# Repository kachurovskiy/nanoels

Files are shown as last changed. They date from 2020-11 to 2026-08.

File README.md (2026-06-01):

This software and instructions are [provided as is](LICENSE), without warranty of any kind. [🇷🇺 Перевод на русский](https://translate.google.com/translate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), [🇩🇪 deutsche Übersetzung](https://translate.google.com/translate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)

**Design lathe parts in the browser with [LatheCode](https://kachurovskiy.com/lathecode/):** start from sample shapes, dimensions, drawings, saved profiles, or STL meshes; preview the result in 2D/3D; then export STL or G-code for machining. It fits naturally with NanoELS and Modulathe workflows: design the turned profile, inspect the generated toolpath, and run or save G-code for your controller, with drafts and settings kept locally in your browser.

# NanoEls H5

CNC and electronic lead screw controller based on ESP32-S3 that supports up to 3 axes:

- All the features of H4
- Cheaper and much easier to make than H4
- External PS2 keyboard
- High resolution touch screen
- More ports: joystick, MPGs, scales



See [h5 folder for hardware files, software and assembly](https://github.com/kachurovskiy/nanoels/tree/main/h5).

# NanoEls H4

CNC and electronic lead screw controller based on ESP32-S3 that supports up to 4 axes:

- Automatic threads including multi-start
- Multi-pass turning, facing and cones
- Precise movements, soft limits and much more

h4-600px

See [h4 folder for hardware files, software, assembly and usage manual](https://github.com/kachurovskiy/nanoels/tree/main/h4).

## Build examples

- [fmw626](https://github.com/kachurovskiy/nanoels/discussions/123)
- [Kissys](https://github.com/kachurovskiy/nanoels/discussions/121)

# NanoEls H2

Cheap DIY Electronic Lead Screw (ELS) based on Arduino Nano for metal lathes. No more greasy gear swapping! Control your metal lathe lead screw with a few clicks.

- Set leadscrew pitch for feed or thread
- Soft limits for the carriage
- Multi-start threads in 1 start of the spindle



See [h2 folder for parts list, software, assembly and usage manual](https://github.com/kachurovskiy/nanoels/blob/main/h2/). Controller can be built from [generally available components](https://github.com/kachurovskiy/nanoels/tree/main/h2#components).

It's suggested to use STEPPERONLINE CL57T closed-loop driver with NEMA 23 3NM motor or stronger with 200 step resolution mode (full step) and a 600 PPR optical rotary encoder. [See hardware.md for more info.](hardware.md)

## Build examples

- [EdFleta](https://github.com/kachurovskiy/nanoels/discussions/87)
- [fmw626](https://github.com/kachurovskiy/nanoels/discussions/118)
- [Johannmupa](https://github.com/kachurovskiy/nanoels/discussions/89)
- [kachurovskiy](https://youtu.be/jR4tBBHSl3c?t=62)

# Contributing to the project

- Questions, problems and improvements: please start [a new GitHub Discussion](https://github.com/kachurovskiy/nanoels/discussions/new) or a new Issue
- Successful builds: please start a new GitHub Discussion with photos and comments

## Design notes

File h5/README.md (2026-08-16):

# NanoEls H5

Latest version of the electronic lead screw controller for metal lathes - https://www.youtube.com/watch?v=dgiMwlfZPNg

h5

## Parts list

- 67€ Nextion 5 inch display [NX8048P050 011C Y](https://www.aliexpress.com/item/1005002457232503.html)
- 10€ [5V 2A non-USB power adapter](https://www.amazon.de/dp/B09KNFD38L)
- 5€ [ESP32-S3 N16R8 weld](https://www.aliexpress.com/item/1005005051294262.html)
- 2€ [SN74HCT245N](https://www.aliexpress.com/item/1005007118898020.html) - pack of 10, we only need 2
- 6€ 3 packs of [5 pairs 3.5mm terminals 4P straight](https://www.aliexpress.com/item/1005006895741900.html)
- 3€ [USB C male to female](https://www.aliexpress.com/item/1005007549815957.html)
- 5€ [custom PCB](pcb/Gerber_PCB_NanoElsH5-20241218.zip) ordered on jlcpcb.com
- [3D-printed case](case/h5case.step) with [SD card handle](case/h5sdhandle.step)
- 5x M3 bolts 5-8mm length
- Optional 19€ [PS2 mini keyboard](https://www.amazon.de/gp/product/B01MRJQVZP)
- Optional 1€ [curved 4-pin header](https://de.aliexpress.com/item/1005007569841697.html) to connect display wires to the PCB

## Display options

You can use any other Nextion display model including cheaper and smaller ones without touch.

- Requires re-compiling the `h5.tft` file from the [h5.HMI](https://github.com/kachurovskiy/nanoels/blob/main/h5/screen/h5.HMI) for your display
- Needs custom 3D-printed case since `case/h5case.step` will no longer fit

## Ordering PCB

1. Go to https://cart.jlcpcb.com/quote, click "Add gerber file"
2. Use Gerber ZIP file supplied in https://github.com/kachurovskiy/nanoels/tree/main/h5/pcb/
3. Select `LeadFree HASL` and `Global Standard Direct Line` shipping
4. Should cost 5€ and arrive within 2 weeks

## Schematics and PCB component placement

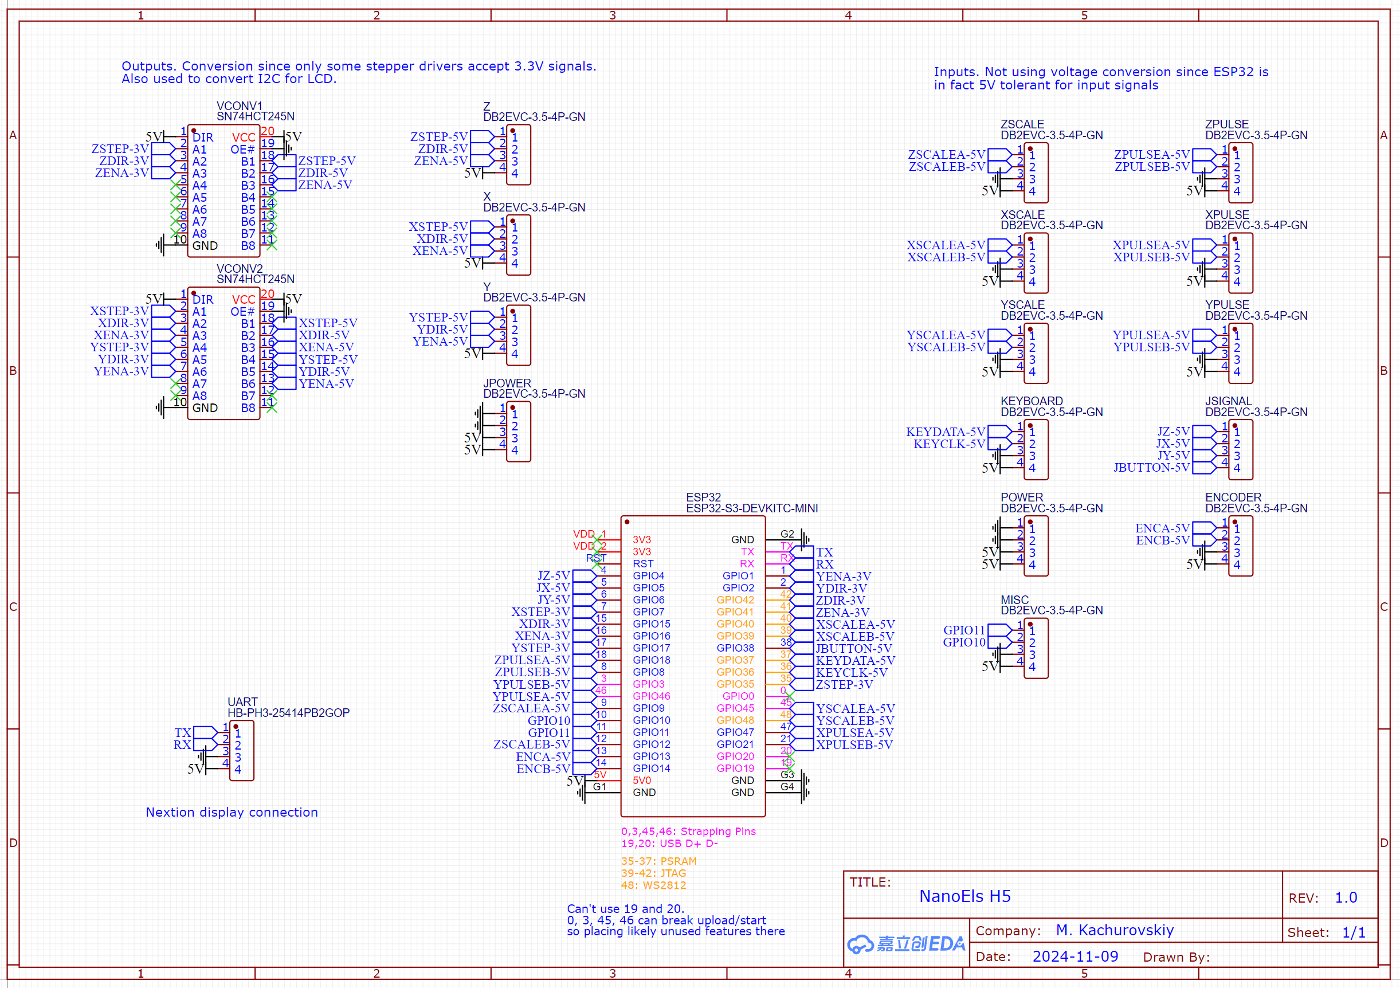
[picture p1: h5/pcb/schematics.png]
schematics






## Install firmware from .bin

Download the latest firmware files from this folder on GitHub:

- Use `h5.ino.YYYYMMDD.merged.bin` for first-time USB flashing of a blank ESP32, or when you need to replace the bootloader, partition table, and firmware together. Flash it at address `0x0`.
- Use `h5.ino.YYYYMMDD.bin` for normal firmware updates after the ESP32 already has the NanoEls bootloader and partition table installed. This is the file to upload in the H5 Web UI under `ESP32 Firmware Upload`.

Precompiled firmware binaries include third-party Arduino/ESP32 components; see [THIRD_PARTY_NOTICES.md](THIRD_PARTY_NOTICES.md) for license notices and rebuild/relink information.

Flash the firmware before soldering the ESP32 onto the H5 PCB. Connect a USB cable directly to the ESP32 board `COM` port and open [Espressif esptool-js](https://espressif.github.io/esptool-js/) in Chrome. For a new ESP32, connect and upload `h5.ino.YYYYMMDD.merged.bin` at address `0x0`.

flash-bin

## Assembly instructions

NOTE: throughout the assembly make sure to avoid static electricity accumulation on your body by wearing suitable clothes and shoes, not using chairs known to cause ESD. Touch any grounded metal device housing to check.

1. Check that ESP32 board is working by uploading firmware onto it as per instructions above.
1. Solder ESP32, 2x SN74HCT245N and optional curved 4-pin header onto the PCB. **Triple check the side and orientation of each piece before soldering.**
1. Insert USB extension into the COM port
1. Separate all terminals into 2 pieces. Insert female terminals into the 3D-printed housing. Place the PCB on top and secure it with 4 M3 bolts. Secure the other end of the USB cable in the access hole with an M3 bolt.
1. Solder 15 terminals to the PCB while everything is positioned in the case.
1. Remove screen back cover. Attach the included 4-lead wire to the screen and to the PCB - each `RX` should be attached to `TX` on the other side.
1. Move dynamic from screen back cover to the main Nextion PCB - e.g. add 3 drops of hot glue and place the dynamic on them with a hard steel side (soft side up)
1. Bolt the case and screen together using the bolts that used to hold the back cover.
1. Supply up to 2A of power to the `POWER` terminal. USB power is enough for flashing the bare ESP32, but 0.5A provided by standard USB is not enough to start the screen.
1. Upload [h5.tft](screen/h5.tft) to the display over WiFi. See [Upload screen .tft over WiFi](#upload-screen-tft-over-wifi).
1. Cut the keyboard cord to the suitable length, find which color corresponds to which line in your particular keyboard [using the port pinout](https://en.wikipedia.org/wiki/PS/2_port) and multimeter continuity tester.

## Upload screen .tft over WiFi

The normal display update path is the H5 Web UI. The MicroSD method is kept as a fallback at the end of this README.

1. Keep the controller stopped and power the screen from the `POWER` terminal.
2. On first boot, connect your computer or phone to the `NanoEls-H5-Setup` WiFi network using password `nanoels-h5`, then open `http://192.168.4.1`.
3. If the controller is already connected to your normal WiFi, open the IP address shown on the H5 screen, in your router, or in the Arduino serial monitor.
4. In `Nextion TFT Upload`, select [h5.tft](screen/h5.tft).
5. Leave `First upload / factory display` checked for a new 9600-baud Nextion. Uncheck it only when the display is already running the uploaded 115200-baud H5 screen.
6. Keep the browser page open until the upload finishes and the display restarts.

## First power-up checks

- Spindle direction: rotate the chuck forward manually - angle on screen should increase. If it decreases, swap `B` and `A` wires in the terminal.
- Motor direction: try moving motors using keyboard arrows - if a motor is moving in the wrong direction, change `Invert direction` for that axis in the Web UI `Machine Config`, save and restart. You can also swap the motor leads `A+` and `A-` in the stepper driver if it is open loop.

## Rear label

Print [h5.pdf](case/h5.pdf) on a normal printer as A4 at 19% scale, cut out and glue to the back of the case using e.g. double-sided tape.

If you want, you can modify the label by editing [h5.fig](case/h5.fig) file on figma.com and export a new PDF for printing.

## Wiring

ENCODER terminal:

- 5V - connect to encoder power-in line (usually red)
- GND - connect to encoder power-in line (usually black) and wire shielding if there's any
- ENCB - connect to one of the encoder signal lines
- ENCA - connect to one of the encoder signal lines

Z and X axes - stepper terminal for the lead screws:

- 5V - connect to stepper driver PUL+, DIR+, ENA+ and wire shielding if there's any
- ENA - connect to stepper driver ENA-
- DIR - connect to stepper driver DIR-
- STEP - connect to stepper driver PUL-

Pulse motion wheels for Z, X, and optional Y axes (`ZPULSE`, `XPULSE`, `YPULSE`) are wired in the same manner as the encoder. For any encoder terminal, switch `A` and `B` wires to invert the encoder direction.

### Optional joystick

- 14€ [D400B-M4](https://de.aliexpress.com/item/1005003970393584.html)
- 5€ [custom PCB](https://raw.githubusercontent.com/kachurovskiy/nanoels/refs/heads/main/h5/joystick/Gerber_PCB_JoystickH5_2026-05-14.zip) ordered on jlcpcb.com
- 2€ [6-pin terminal](https://de.aliexpress.com/item/1005006895741900.html)
- 2€ [5V to 3V regulator LM1117T-3.3](https://de.aliexpress.com/item/1005005691591247.html)
- [3D printed joystick case parts](https://github.com/kachurovskiy/nanoels/tree/main/h5/joystick)
- [4xM3 10mm bolts](https://github.com/user-attachments/assets/4981138c-4b91-403d-91d5-b71684435139)

Joystick is optional, and disabled by default in `h5.ino`. A 1-, 2-, or 3-axis potentiometer joystick is supported. Enable joystick support only after wiring the joystick, and enable only the joystick inputs that are actually connected:

- `JSIGNAL` carries signals only: `JZ`, `JX`, `JY`, `JBUTTON`
- Power the joystick potentiometers from `JPOWER` 5V through a resistor divider that brings the joystick supply down to about 3.3V, or use a small 3.3V regulator sharing controller `GND`; do not feed 5V into the potentiometers because the ESP32 ADC pins are not 5V analog inputs
- Connect each potentiometer wiper to the matching `JZ`, `JX`, or `JY` signal. Leave missing axes disconnected and disable the matching `Z input enabled`, `X input enabled`, or `Y input enabled` checkbox in the Web UI `Machine Config`
- Connect the joystick button between `JBUTTON` and `GND`
- Leave enabled joystick axes centered while powering on. If joystick support is enabled while the joystick is unplugged or any enabled axis is not centered at startup, H5 ignores joystick input until the next restart
- Disabled joystick axes are treated as neutral. Z and X inputs behave like proportional handwheel input for their matching machine axes. Y input adjusts pitch in modes that allow joystick pitch changes; when it is not used for pitch, Y moves the optional machine Y axis if `ACTIVE_Y` is enabled. Holding the button enables rapid motion for manual joystick moves
- In `JOY` mode, use `ON`/`OFF` as the feed clutch. With feed off, Z/X deflection jogs the carriage or cross-slide normally. With feed on, Z/X deflection commands spindle-synchronized feed using the configured pitch magnitude. Pressing the joystick button while Z or X is deflected performs rapid movement. If `Button toggles ON/OFF` is enabled, a short button click while Z and X are neutral toggles the feed clutch. After the first feed engagement, `JOY` preserves the thread phase and waits for the correct spindle angle before later feed engagements.

**WARNING:** disconnecting joystick when controller is powered on can lead to random movements due to floating analog inputs.

## Scale terminals

Scale terminals aren't used in the code yet.

## Mounting options

On the back of the case there are 2 holes for M5 threaded inserts 130mm on center.

## GCode over WiFi for complex parts

WiFi credentials are configured in the H5 Web UI and stored in ESP32 Preferences. On first boot, or when the saved network cannot be reached, NanoEls starts a setup access point:

- Network: `NanoEls-H5-Setup`
- Password: `nanoels-h5`
- Web UI: `http://192.168.4.1`

Open the Web UI, fill in the `WiFi` section, click `Save and restart`, then connect through the IP address shown on the H5 screen or Arduino serial monitor. The Web UI can be used to save GCode files onto the controller and run them later at the machine in the GCODE mode.

Firmware and screen uploads use the same Web UI described above. Anyone on the local network can access the Web UI, so only enable WiFi on a trusted network.

The Web UI also has a `Machine Config` section for encoder, Z/X/Y axis, handwheel, manual stepping, and joystick parameters. Save changes only while the controller is stopped; NanoEls stores them in ESP32 Preferences and restarts to apply them.

The `Keyboard` section lets you change PS/2 keyboard key-code mapping, learn key codes from the connected keyboard, and toggle showing key presses on the Nextion screen. Keyboard mapping is stored in ESP32 Preferences and takes effect without recompiling firmware. GPIO pin mapping still requires editing `h5.ino`.

### Experimental Web Control UI

The Web UI includes an experimental `Control` tab for phones and tablets. It can be used as an optional control surface when you prefer not to use a PS/2 keyboard or when you do not have a suitable touch Nextion screen. The controller still runs all motion logic locally on the ESP32; the browser only sends button actions and shows status.

Use it with the same caution as any other machine-control input:

- Treat the Web Control UI as experimental. Test every button, axis direction, stop, and mode with motors clear of the work before cutting.
- Keep a physical power switch, emergency stop, or stepper-driver enable cutoff within reach. Do not rely on WiFi, a browser tab, or a touchscreen as the only way to stop motion.
- Use it only on a trusted local network. Anyone who can reach the Web UI can control the machine.
- Keep the controller stopped before changing WiFi, firmware, screen, machine config, or keyboard settings.
- Avoid using Web Control for unattended operation. Phone sleep, browser reloads, weak WiFi, or moving out of range can interrupt the UI even though the controller has failsafes for held jog buttons.
- Check the on-machine screen/controller state when anything looks wrong or delayed. If in doubt, stop the controller physically before continuing.

UI options such as Accessibility are in the Web UI `UI` tab. They are browser-local, stored in `localStorage`, and do not use the firmware Save/Reset flow. Voice feedback uses the browser Web Speech API.

To generate GCode for your parts, upload STL model of your part to https://kachurovskiy.com/lathecode/ and specify parameters like stock diameter and tool used.

Handwheels and limits have no effect when GCODE is running.

### Supported GCode commands

NanoEls implements a small uppercase RS274/GRBL-style subset for lathe work. Coordinates and feed values use the current GCode unit mode: `G21` for millimeters or `G20` for inches. GCODE mode starts in absolute positioning (`G90`) with the firmware default feed rate. Use one command per line when possible.

Motion commands:

- `G0`, `G00`, `G1`, `G01` - linear move on `X`, `Z`, and optionally `Y`. `G0` and `G1` use the same interpolation and feed handling. `F` sets feed in current units per minute and may be supplied on the move line, for example `G1 X12.5 Z-3 F120`.
- `X...`, `Z...`, or `Y...` without a leading `G` - treated as a `G0`/`G1` move.
- `G32` - single-pass spindle-synchronized threading move. `F` is the thread lead per spindle revolution in current units, not feed per minute. `F` must be positive; the thread direction comes from the axis movement direction, for example `G32 Z-10 F1.5`.

Mode and setup commands:

- `G20` - use inch units.
- `G21` - use metric units.
- `G90` - absolute positioning.
- `G91` - relative positioning.
- `G94` - feed-per-minute mode; accepted as a no-op because this is already how feed is handled for `G0`/`G1`.
- `G18` - ZX plane selection; accepted as a no-op.

Other accepted commands:

- `F...` - set the modal feed rate for later `G0`/`G1` moves.
- `M0`, `M1`, `M2`, `M30` - stop/end the running GCode program.
- `T...` - accepted and ignored.

Supported syntax:

- Optional line numbers like `N10 G1 X1 Z2`; the `N...` prefix must be followed by a space.
- Comments in `(parentheses)` or after `;` until the end of the line.
- `%` program start/end markers are accepted and ignored.
- `Y` moves only work when the optional Y axis is enabled with `ACTIVE_Y`.

h5v26

## Custom keyboard mapping

Keyboard key-code mapping is configurable from the H5 Web UI and does not require rebuilding `.bin` files.

1. Open the H5 Web UI through the setup access point or the controller IP address.
2. Keep the controller stopped.
3. In the `Keyboard` section, use `Learn` next to an action, then press the physical keyboard key you want to assign. The learned PS/2 key code is filled in automatically.
4. Alternatively, type a key code manually in the action's number field.
5. Enable `Show key presses on screen` if you want the Nextion bottom line to show the last physical key code while testing a keyboard.
6. Click `Save keyboard`. The new mapping is stored in ESP32 Preferences and takes effect immediately.

`Reset keyboard` restores the firmware default mapping.

## Usage manual

The controller can be controlled via touchscreen and/or keyboard. Keyboard is optional but it's much nicer to use mechanical buttons for manual moves and not worrying about accidentally pressing a nearby button on the touchscreen.

### Touchscreen

If descriptions of the buttons below are unclear, don't worry, skip this section and read the rest of the manual, that should clarify things.

h5v11screen

Top line:

- `bStatus` turns the controller off - stops the ongoing operation or manual move, resets spindle angle and turns to 0
- `bMode` turns the controller off and changes the mode
- `mMultistart` increases the number of starts by 1 when pressed in short intervals, sets the number of starts to 1 if pressed after a pause
- `tPitch` reverses the pitch - makes it positive if it's negative, makes it negative if it's positive. In gearbox modes, reversing while ON keeps the current spindle/axis phase so the controller stays in the thread.
- `bMeasure` changes measuring system between metric, imperial and tpi
- `mPlus` increments the pitch or number of passes in a multi-pass operation
- `mMinus` decrements the pitch or number of passes in a multi-pass operation

Middle line:

- `tStepVal` toggles between different step sizes used in manual moves
- `tRPMVal` shows current rotations per minute of the spindle
- `tTurnsVal` shows the number of full turns performed by the spindle since the last off/stop command
- `tAngleVal` shows the current angle of the spindle

X axis group:

- `mXUp` and `tXUp` clear the up limit if it's set, sets the limit in the current `X` position if it's not set
- `bX` enables or disables the axis. When pressed with active numpad input, considers the input as measured diameter of the part at current cutter position and sets `X` zero to negative half of the given diameter.
- `tX` take current `X` position as zero
- `mXDown` and `tXDown` clear the down limit if it's set, sets the limit in the current `X` position if it's not set
- `m0` moves cross-slide forward
- `m1` moves cross-slide back

Y axis group:

- `mYUp` and `tYUp` clear the positive `Y` limit if it's set, sets the limit in the current `Y` position if it's not set
- `bY` enables or disables the axis
- `tY` take current `Y` position as zero
- `mYDown` and `tYDown` clear the down limit if it's set, sets the limit in the current `Y` position if it's not set
- `m2` moves `Y` axis forward
- `m5` moves `Y` axis back

Z axis group:

- `m3` and `tZLeft` clear the left limit if it's set, sets the limit in the current `Z` position if it's not set
- `bZ` enables or disables the axis
- `tZ` take current `Z` position as zero
- `m4` and `tZRight` clear the right limit if it's set, sets the limit in the current `Z` position if it's not set
- `m6` moves the carriage left
- `m7` moves the carriage right

Lower part of the screen:

- `t3` shows diameter, current WiFi status, pending numpad value or mode configuration prompt
- `mStop` turns the controller off
- `bD0` to `bD9` append a number at end of the numpad input
- `mBack` works as backspace - deletes the last entered number
- `mPlay` starts the current mode or proceeds to the next step of mode configuration

### Keyboard

- ⌨️`Left`, ⌨️`up`, ⌨️`down`, ⌨️`right` arrows control the manual movement
- ⌨️`Plus` / ⌨️`minus` control the pitch
- ⌨️`Enter` turns on the current mode
- ⌨️`Esc` is stop
- ⌨️`A` / ⌨️`W` / ⌨️`D` / ⌨️`S` control limits
- ⌨️`Win` controls angle / rpm display / WiFi status
- ⌨️`Tilda` / ⌨️`backtick` (key under ESC) controls step
- ⌨️`M` changes metric / inch / tpi
- ⌨️`R` for reverse
- Top row numbers ⌨️`0`-⌨️`9` work as number input
- ⌨️`Backspace` removes last number
- Modes:
  - ⌨️`F1`: gearbox
  - ⌨️`F2`: turning
  - ⌨️`F3`: facing
  - ⌨️`F4`: cone
  - ⌨️`F5`: parting
  - ⌨️`F6`: threading
  - ⌨️`F7`: async
  - ⌨️`F8`: ellipse
  - ⌨️`F9`: gcode
  - ⌨️`F10`: y axis (if configured)
  - ⌨️`F11`: cycle modes
  - ⌨️`F12`: joystick lathe mode
- ⌨️`X` zeroes X axis
- ⌨️`Z` zeroes Z axis
- ⌨️`C` disables / enables X axis
- ⌨️`Q` disables / enables Z axis
- ⌨️`O` pressed while a number is entered zeroes X from diameter

### Convention for referring to screen or keyboard buttons in this manual

Text like 🖥️`bMeasure` refers to looking at or pressing on the corresponding area of the screen, in this case green "IN" rectangle in the upper-right part of it.

Text like ⌨️`M` refers to pressing the corresponding letter on the keyboard, in this case letter M.

Dash between symbols refers to all the buttons between the 2 mentioned buttons e.g. ⌨️`1`-`0` means `1`, `2`, `3`, `4`, `5`, `6`, `7`, `8`, `9`, `0` keys on the keyboard.

Slash between symbols refers to either one of the symbols e.g. ⌨️`+`/`-` means "pressing plus or minus key on the keyboard".

### Switching between metric and imperial

Press 🖥️`bMeasure` or ⌨️`M`  to change the system of measurement between:

- Metric (mm)
- Inch
- TPI

It affects how the pitch and position is displayed and changes, move steps for precision moves.

### Setting pitch

Pitch is the distance that carriage will move when the spindle makes the full turn. For example, M14 thread uses 2mm pitch.

Use numpad buttons 🖥️`bD0`-`bD9` or ⌨️`1`-`0` to enter the pitch value, 🖥️`mPlay` or ⌨️`Enter` to accept it.

Adjust the desired pitch using 🖥️`mPlus`/`mMinus` or ⌨️`+`/`-`.

Use negative pitch values e.g. `-2mm` to cut left-to-right threads. To change the pitch sign, press 🖥️`tPitch` or ⌨️`R`.

### Setting step

Step setting is used for manual carriage moves in `off` state - i.e. when no mode is active and no thread is being cut. Current step setting is normally shown in 🖥️`tStepVal`.

Pressing 🖥️`tStepVal` or ⌨️`Key under ESC` cycles through the list of predefined steps:

- Metric: `1mm`, `0.1mm`, `0.01mm`
- Imperial: `0.1"`, `0.01"`, `0.001"`

Use 🖥️`bD0`-`bD9` or ⌨️`1`-`0` to enter a custom step value. Pressing 🖥️`tStepVal` or ⌨️`Key under ESC` when the screen bottom line shows `Use 1.234mm?` will make the step equal to `1.234mm`.

### Zeroing the axes

Z and X position can be counted from any location you'd like. By pressing e.g. 🖥️`tZ` or ⌨️`Z` you can take the current position on the respective axis as `0`.

You can also set the `0` at a position ahead of the current position by entering the required distance using the numpad buttons 🖥️`bD0`-`bD9` or ⌨️`1`-`0` and then pressing 🖥️`tZ` or ⌨️`Z`.

You can set X0 on the lathe centerline by making a light cut, measuring diameter, entering it on the numpad and then pressing 🖥️`bX` or ⌨️`O`.

### Moving left and right, in and out

Press 🖥️`m6`/`m7` / ⌨️`Left`/`Right` buttons to move the carriage, 🖥️`m0`/`m1` / ⌨️`Up`/`Down` to move the cross-slide.

Depending on the state of the controller, pressing the move button will result in traveling the following distance:

- `off` - carriage will move by the step distance but at least 1 stepper motor step
- `ON` - carriage will move in pitch increments (stay in the thread) but at least the step distance

If step is set to `1mm` or `0.1"`, pressing and holding move buttons results in continuous movement allowing for quick tool positioning when the Web UI `Machine Config` setting `Enable continuous moves` is enabled. If it is disabled, or if step is set to values other than `1mm` or `0.1"`, there's a short delay between steps when manual moves are triggered allowing to precisely position the tool.

Changing direction will result in automatic backlash compensation, for example with backlash `0.65mm` and step `0.1mm`, first move in the opposite direction will result in lead screw turning `0.75mm`. Tool should still only move `0.1mm` assuming backlash is uniform and is specified correctly.

When `off`, use numpad buttons 🖥️`bD0`-`bD9` / ⌨️`1`-`0` to enter a custom move distance. Pressing a move button when the screen bottom line shows `Use 1.234mm?` will move `1.234mm` in the corresponding direction. If there's an automatic stop limiting travel, it will move up to the limit and beep.

### Soft limits / automatic stops

Soft limits allow to cut close to the lathe chuck, part shoulder or rear support without hitting them.

One way to set a soft limit is to move the carriage or cross-slide to the desired position and press one of the 🖥️`tZLeft`/`tZRight`/`tXUp`/`tXDown` / ⌨️`A`/`W`/`D`/`S` limit buttons. Pressing the button again removes the limit regardless of the current position.

Another way to set a soft limit is to use numpad buttons 🖥️`bD0`-`bD9` / ⌨️`1`-`0` to enter a distance relative to the current position. Pressing a limit button when the screen bottom line shows `Use 1.234mm?` will set corresponding limit `1.234mm` away from the current position.

Soft limits are used when preparing an automatic operation like turning, facing, threading and cutting off.

### Gearbox mode / electronic lead screw

Press 🖥️`bMode` to switch to the gearbox mode. After turning the controller `ON` with the 🖥️`mPlay` / ⌨️`Enter` button, lead screw will move the distance of 1 pitch for 1 spindle turn.

`XGEAR` works the same way but couples the spindle to the `X` axis instead of `Z`, so the cross-slide moves the distance of 1 pitch for 1 spindle turn. Use ⌨️`F11` mode cycling or the touchscreen mode page to switch to `XGEAR`.

With a small pitch like `0.07mm` this mode is useful for turning - gradually taking off material from the outer diameter of the part.

With a large pitch like `0.5"` one can cut a corresponding thread. Moving with 🖥️`m6` and 🖥️`m7` buttons is supported and does not result in losing the thread.

Direction of movement can be quickly reversed with 🖥️`tPitch` / ⌨️`R` button which toggles the pitch sign. Negative pitch can also be used to cut left threads.

Soft limits are respected in this mode allowing to finish the cut in a precise position.

Cross-slide can be moved with manual move buttons or disabled using 🖥️`bX` / ⌨️`C` and be operated manually.

In `XGEAR`, the carriage can be moved with manual move buttons or disabled using 🖥️`bZ` / ⌨️`Q` and be operated manually.

Press 🖥️`mStop` / ⌨️`Esc` to turn gearbox mode `off` and decouple lead screw movements from spindle turns.

### Joystick lathe mode

Switch to `JOY` with ⌨️`F12`. This mode requires joystick support to be enabled. Enable the Z and/or X joystick inputs for the axes you want to feed; disabled joystick inputs stay neutral.

Set the desired pitch magnitude first and use `ON` / `OFF` as the feed clutch. When `JOY` is `ON`, moving the enabled Z joystick left/right feeds the carriage left/right at that pitch per spindle revolution. Moving the enabled X joystick in/out feeds the cross-slide in/out at the same pitch magnitude. The pitch sign is ignored in this mode; joystick direction selects the cut direction.

Move the enabled joystick Y axis to permanently change the configured pitch like holding `+` or `-`. This also works outside `JOY` while the controller is `OFF`, and while compatible modes are `ON` such as `GEAR`, `XGEAR`, `TURN`, `FACE`, `CUT`, `CONE`, `ASYNC`, and `Y`. Joystick Y does not adjust pitch in `GCODE` or while `THREAD` or `ELLIPSE` operations are running. Larger Y deflection changes pitch faster.

When `JOY` is off, moving the enabled Z or X joystick input jogs the carriage or cross-slide normally. Press and hold the joystick button while Z or X is deflected to rapid-traverse in that direction. If `Button toggles ON/OFF` is enabled, a short button click while Z and X are neutral toggles `ON` / `OFF`; longer presses or clicks made while Z/X are deflected do not toggle.

For manual multi-pass threading, the first feed engagement establishes the thread phase. Later passes stay in that thread: after you retract, return the carriage, and engage feed again, the controller shows `Sync` and waits for the matching spindle phase before moving the carriage. The operator does not need to track spindle angle.

Soft limits are respected for synchronized feed and rapid movement.

### Automatic turning

Press 🖥️`bMode` to switch to the automatic turning mode which is usually used to take large amount of material from the inside or outside diameter of the part in multiple passes.

Set the desired pitch to a suitable value e.g. `0.05mm`. Negative pitch will make turning start from the left limit, positive pitch will make it start from the right. All soft limits (left, right, up, down) must be set before the operation can be started.

Pressing 🖥️`mPlay` / ⌨️`Enter` guides through remaining steps:

- Entering the number of passes - use numpad or 🖥️`mPlus`/`mMinus` / ⌨️`+`/`-`, confirm with 🖥️`mPlay` / ⌨️`Enter`
- Selecting `External` or `Internal` operation - use 🖥️`m6` and 🖥️`m7` to change selection. Internal operations start from the 🖥️`tXUp` limit, external from the 🖥️`tXDown` limit. Confirm with 🖥️`mPlay` / ⌨️`Enter`
- Confirm the final `Go?` question with 🖥️`mPlay` / ⌨️`Enter`

Turn on the spindle. Operation will proceed fully automatically and the cutter will return to the starting position when done. Pitch can be adjusted on the fly using 🖥️`mPlus`/`mMinus` / ⌨️`+`/`-`.

You can skip to the next pass using 🖥️`mPlay` / ⌨️`Enter` while the operation is running.

Operation can be stopped at any time by pressing 🖥️`mStop` / ⌨️`Esc` or using manual move buttons.

In previous versions cross-slide would pull back all the way between the passes, starting from H5V12 we only pull back by a small safe distance.

Handwheels are ignored when this mode is on.

### Automatic facing

Press 🖥️`bMode` to switch to the automatic facing mode which is usually used to take large amount of material from the face of the part in 1 or more passes.

It's setup in the same way as automatic turning above. When running, passes are made along the face instead of the side of the part. Negative pitch will make facing start from the inside.

### Cone

Press 🖥️`bMode` to switch to the cone mode which maintains a constant ratio of movement between the X and Z axes. Cone mode doesn't require soft limits to be set but if they are set, they are respected.

Pressing 🖥️`mPlay` / ⌨️`Enter` guides through the setup:

- Enter cone ratio which is calculated as `(major_diameter - minor_diameter) / length`, see [this spreadsheet for most used values](https://docs.google.com/spreadsheets/d/1l0FUMtlWUjPywN9j94DOL84lB8dFrvdRWZIffT2NoHA/edit?usp=sharing). Confirm with 🖥️`mPlay` / ⌨️`Enter`
- Select `External` or `Internal` cone - use 🖥️`m6` and 🖥️`m7` to change selection. Confirm with 🖥️`mPlay` / ⌨️`Enter`

Turn on the spindle. Pitch can be adjusted on the fly using 🖥️`mPlus`/`mMinus` / ⌨️`+`/`-`. It's convenient to cut multiple cone passes with 🖥️`tPitch` / ⌨️`R` moving the tool in using manual move buttons.

### Automatic cut-off

Press 🖥️`bMode` to switch to the automatic parting mode which gradually feeds the cross-slide into the part from outside or inside in one or multiple passes.

Set the desired pitch to a suitable value e.g. `0.05mm`. Negative pitch will make turning start from the inside, positive pitch will make it start from the outside. 🖥️`tXUp` and 🖥️`tXDown` soft limits must be set before the operation can be started.

Pressing 🖥️`mPlay` / ⌨️`Enter` guides through remaining steps:

- Entering the number of passes - use numpad or 🖥️`mPlus`/`mMinus` / ⌨️`+`/`-`, confirm with 🖥️`mPlay` / ⌨️`Enter`
- Check that pitch corresponds to the desired direction of cutting, click 🖥️`tPitch` / ⌨️`R` to change it
- Confirm the final `Go?` question with 🖥️`mPlay` / ⌨️`Enter`

Turn on the spindle. Operation will proceed fully automatically and the cutter will return to the starting position when done. Pitch can be adjusted on the fly using 🖥️`mPlus`/`mMinus` / ⌨️`+`/`-`.

Operation can be stopped at any time by pressing 🖥️`mStop` / ⌨️`Esc` or using manual move buttons.

Handwheels are ignored when this mode is on.

### Automatic slotting

Press `bMode` until `SLOT` is shown. Slotting moves the cutter in on X, feeds Z to the left, retracts X, then returns Z to the right. The spindle does not drive this mode; only Z and X move.

All Z and X soft limits must be set before the operation can be started. The number of passes controls the X increments between the selected internal or external start and end limits. Pitch magnitude is used as the left feed distance per second and can be adjusted while slotting is running. Setting pitch to 0 pauses the left feed until pitch is increased again. X moves and the return to the right use the configured manual move speeds.

The Web UI setting `Slot left reduction` defaults to 0. For blind slots, increase it slightly to shorten each successive left cut and leave space for chip accumulation near the blind end.

### Automatic threading

Press 🖥️`bMode` to switch to the automatic threading which will cut a thread (optionally multi-start one) in multiple passes.

First passes are larger than average, final passes are shallower.

Set the desired pitch to a suitable value e.g. `2mm` or `20tpi`. Negative pitch will result in a left thread and will make the operation start from the left limit, positive pitch will make the operation start from the right. All soft limits (left, right, up, down) must be set before the operation can be started.

Pressing 🖥️`mPlay` / ⌨️`Enter` guides through remaining steps:

- Entering the number of passes - use numpad or 🖥️`mPlus`/`mMinus` / ⌨️`+`/`-`, confirm with 🖥️`mPlay` / ⌨️`Enter`
- Selecting `External` or `Internal` operation - use 🖥️`m6`/`m7` or ⌨️`Left`/`Right` to change selection. Internal operations start from the 🖥️`tXUp` limit, external from the 🖥️`tXDown` limit. For multi-start thread, press 🖥️`mPlus` to add more starts. Confirm with 🖥️`mPlay` / ⌨️`Enter`
- Enter optional cone ratio on the numpad. Confirm with 🖥️`mPlay` / ⌨️`Enter`
- Confirm the final `Go?` question with 🖥️`mPlay` / ⌨️`Enter`

Turn on the spindle. Operation will proceed fully automatically and the cutter will return to the starting position when done.

You can skip to the next pass using 🖥️`mPlay` / ⌨️`Enter` while the operation is running.

Operation can be stopped at any time by pressing 🖥️`mStop` / ⌨️`Esc` or using manual move buttons.

### Automatic half-spheres and half-ellipses

Press 🖥️`bMode` several times until `ELLI` is shown on screen. In this mode, cutter will form convex or concave half-ellipses in multiple passes.

Starting operation with positive pitch forms left hemisphere, with negative pitch - right hemisphere. This ensures that X backlash doesn't affect the cut.

`External` mode forms convex hemisphere (curved outward), `Internal` forms concave hemisphere (curved inward). Start and end points are the same in both cases.

Set the desired pitch to a suitable value e.g. `0.07mm`. All soft limits (left, right, up, down) must be set before the operation can be started.

Pressing 🖥️`mPlay` / ⌨️`Enter` guides through remaining steps:

- Entering the number of passes - use numpad or 🖥️`mPlus`/`mMinus` / ⌨️`+`/`-`, confirm with 🖥️`mPlay` / ⌨️`Enter`
- Selecting `External` or `Internal` operation - use 🖥️`m6`/`m7` / ⌨️`Left`/`Right` to change selection. Confirm with 🖥️`mPlay` / ⌨️`Enter`
- Confirm the final `Go?` question with 🖥️`mPlay` / ⌨️`Enter`

Turn on the spindle. Operation will proceed fully automatically and the cutter will return to the starting position when done. Adjusting the pitch on the fly is not supported.

Operation can be stopped at any time by pressing 🖥️`mStop` / ⌨️`Esc` or using manual move buttons.

Handwheels are ignored when this mode is on.

### Async mode

In this mode the carriage disregards spindle movements and instead moves with constant speed of `pitch` per second. When pitch is positive, `Z` axis moves to the left. When pitch is negative, `Z` axis moves to the right. If pitch is 0, `Z` axis doesn't move.

You can adjust the pitch using 🖥️`mMinus`/`mPlus` to adjust the movement speed.

Async mode respects limits if they are set.

## Self-compile firmware with Arduino IDE

Use this path only when you need to change the firmware source or rebuild the `.bin` files yourself.

- Install the [Arduino IDE](https://docs.arduino.cc/software/ide-v2)
- Add `https://raw.githubusercontent.com/espressif/arduino-esp32/gh-pages/package_esp32_index.json` in [Preferences as "Additional board manager URLs"](https://github.com/kachurovskiy/nanoels/assets/517919/dcc023e6-20fc-4284-ba56-d466dbe4ce53)
- Install `esp32` [via Board Manager](https://github.com/kachurovskiy/nanoels/assets/517919/094d00ff-1e51-4f26-bb81-aa4ad42bde2a)
  - If you get a `DEADLINE_EXCEEDED` error while installing `esp32`, [see this post for a workaround](https://forum.arduino.cc/t/ide-2-3-7-now-gives-error-4-deadline-exceeded/1422321/2)
- Install `PS2KeyAdvanced` and `WebSockets` via Arduino IDE Library Manager
- Download [this repository](https://github.com/kachurovskiy/nanoels/archive/refs/heads/main.zip), unzip, go to `h5` directory and open `h5.ino` file in the Arduino IDE
- Check the top constants only if you need to change firmware defaults. Encoder, Z/X/Y axis, handwheel, manual stepping, and joystick parameters can usually be changed later in the Web UI `Machine Config`; PS/2 keyboard mapping can be changed in the Web UI `Keyboard` section.
- Select "ESP32S3 Dev Module" as device at the top, pick the COM port that appears when you connect the device with a USB cable
- Upload the sketch to your H5 controller, or use `Sketch > Export Compiled Binary` to create `.bin` files

For later firmware updates over WiFi, upload `build\esp32.esp32.esp32s3\h5.ino.bin` in the H5 Web UI under `ESP32 Firmware Upload`. Keep the controller stopped during upload. The controller restarts automatically after a successful upload.

To create a full image for first-time USB flashing, use the Arduino build output `build\esp32.esp32.esp32s3\h5.ino.merged.bin` at address `0x0`.

Troubleshooting:

- Arduino IDE doesn't detect NanoEls H5: try a different USB cable
- Arduino IDE fails to upload the sketch: make sure you plugged the extension into the `COM` port, **not** the `USB` port on the ESP32
- WiFi firmware upload fails with an OTA partition or space error: upload over USB after selecting an OTA-capable partition scheme. USB is also required when changing the partition scheme.
- Not sure which COM port is NanoEls H5: unplug it, check the list of available ports in Arduino IDE, plug H5 in, see new port that appeared is H5
- `ImportError: No module named serial` error on Linux: try `sudo apt install python3-serial`

## Upload screen from MicroSD card

Use the MicroSD method only if WiFi upload is unavailable.

1. Format an empty MicroSD card 32 GB or smaller as FAT32.
2. Copy [h5.tft](screen/h5.tft) to the card.
3. Insert the card into the Nextion display.
4. Connect 5V power supply to the `POWER` terminal and wait for the screen to report that flashing has finished.
5. Disconnect the power and remove the card.

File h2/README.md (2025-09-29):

This software and instructions are provided as is, [without warranty of any kind](LICENSE).

# NanoEls H2

This is the second hardware version (hence H2) of NanoEls electronic lead screw controller. It still uses Arduino Nano
microcontroller, a [custom PCB board](https://github.com/kachurovskiy/nanoels/blob/main/h2/Gerber_PCB_NanoElsLcd_20220815.zip) you
can print cheaply on jlcpcb.com and a few widely available components allowing you to build a DIY single-axis ELS.



Features:

- Big screen
- Nice terminals
- Convenient buttons
- Disabling stepper when it's not used (less buzzing)
- Controlling left/right movement step - 1mm, 0.1mm, 0.01mm and 0.001mm
- Higher precision when turning imperial pitches
- Moving left/right while ON
- On/off switch
- Tachometer
- Multi-start threads
- Asynchronous mode
- Metric, inch and TPI support
- Quick reverse

⚠️ Due to Arduino relatively low frequency and realtime requirements (can't plan the motion ahead) H2 can only issue 2800 step impulses per second. This means that the motor can reach ~800 RPM at 200 steps per revolution or ~200 RPM at 800 steps per revolution. Make sure to use a motor with a driver that can do full steps or use the [H5 controller](https://github.com/kachurovskiy/nanoels/tree/main/h5) instead.

## Components

- Arduino Nano (mini USB style)
- 2004 LCD display
- 12 buttons 6x6mm, each 6mm tall
- 8 1kOhm resistors, one 1MOhm resistor (or similar)
- 6 M3 nylon stand-offs (12mm long) and screws
- 3 KF2EDG sockets (Curved needle, 4P, 3.5MM)
- 3 KF2EDG plugs (Plug Terminal, 4P, 3.5MM)
- MTS-102 on-off switch
- RV09 10kOhm potentiometer
- 6 M3 threaded inserts

All of this can easily be found on AliExpress, eBay or Amazon.

## Case

3D models ready for printing: [main case](https://github.com/kachurovskiy/nanoels/blob/main/h2/nanoels-lcd-case.stl),
[lid](https://github.com/kachurovskiy/nanoels/blob/main/h2/nanoels-lcd-lid.stl),
[button](https://github.com/kachurovskiy/nanoels/blob/main/h2/nanoels-lcd-button.stl). You can print it at home or e.g. at [JLCPCB](https://cart.jlcpcb.com/quote).

## Assembly

1. Check that your Arduino Nano is functional before soldering
1. Solder everything except the display onto the PCB, pay attention which side a part should be facing (up/down/left/right) and ensure Arduino pins won't be touching the display later
1. Ensure perfect soldering joints on 1kOhm resistors or the vertical row of buttons won't work well
1. Solder the display
1. Check that your board is working (connect to a PC via Arduino Nano USB port, upload code) before inserting it into the case
1. Push threaded inserts into the case using your soldering iron
1. Drill out the main case button holes using a 7mm drill and ensure the buttons are moving freely
1. Insert buttons into the case, insert PCB, screw in stand-offs (sorry, it's non-trivial), close the lid and screw it to the stand-offs

## Wiring

Starting from the top terminal:

- 5V - connect to 5V power supply positive output (usually red) through an emergency stop button
- GND - connect to 5V power supply negative output (usually black)

Encoder terminal:

- ENCA - connect to one of the encoder signal lines
- ENCB - connect to one of the encoder signal lines
- 5V - connect to encoder power-in line (usually red)
- GND - connect to encoder power-in line (usually black) and wire shielding if there's any

Stepper terminal:

- STEP - connect to stepper driver PUL-
- DIR - connect to stepper driver DIR-
- ENA - connect to stepper driver ENA-
- 5V - connect to stepper driver PUL+, DIR+, ENA+ and wire shielding if there's any

## Schematics

**WARNING:** trying to build this on a breadboard will result in [interference problems](https://github.com/kachurovskiy/nanoels/discussions/89) and will likely make the device unusable. Please use the PCB instead.



## PCB



[Gerber ZIP](https://github.com/kachurovskiy/nanoels/blob/main/h2/Gerber_PCB_NanoElsLcd_20220815.zip)

## Programming the Arduino

- Download the Arduino IDE
- Install `LiquidCrystal` and `FastGPIO` libraries via the Library Manager in the Arduino IDE
- Download [this repository](https://github.com/kachurovskiy/nanoels/archive/refs/heads/main.zip), unzip, go to `h2` directory and open `h2.ino` file in Arduino IDE
- Check the top constants (e.g. encoder steps, motor steps, display offset) and adjust if needed
- Upload the sketch to your Arduino Nano
- Spindle direction: show angle on screen using top-right button. Rotate the chuck forward manually - angle should increase. If it decreases, swap `ENC_A` and `ENC_B` values in the code, re-upload the sketch
- Motor direction: try `LEFT` and `RIGHT` buttons - if motor is moving in the wrong direction, change the value of `INVERT_STEPPER` in the code, re-upload the sketch

# Operating the ELS



## Safety

- **In case of unexpected movements use Emergency Stop button.** Ensure that your Emergency Stop button stops all motion and it can't automatically restart when Emergency Stop is lifted.
- Ensure that your machine complies with all applicable laws and regulations e.g. [Machinery Directive](https://eur-lex.europa.eu/legal-content/EN/TXT/?uri=celex%3A32006L0042) in Europe.
- Test the controller functionality before relying on it. Don't operate machinery without the necessary training and knowledge, in a hurry or when tired.

## Switching between metric and imperial

Use button that is second from the bottom in the vertical row of buttons to change the system of measurement between:

- Metric (mm)
- Inch
- TPI

It affects how the pitch and position is displayed and changes, move steps for precision moves.

## Setting pitch

Pitch is the distance that carriage will move when the spindle makes the full turn. For example, M14 thread uses 2mm pitch.

Select the desired pitch using `-` and `+` buttons. If you keep the buttons pressed, the pitch starts changing faster after a few seconds.

Use negative pitch values e.g. `-2mm` to cut left-to-right threads. Do do that, you have 2 options:

- hold the `-` button until the pitch drops below 0 to the required value
- or press the bottom-right button to toggle the pitch sign between `+` and `-`

Some inch threads require setting the micron part (3rd precision point) of the pitch, to do that click the `Step` button until you're in the `0.001mm` mode. Now clicking `-` or `+` buttons will change the pitch by a micron.

## Turning

- Set desired pitch using `-` and `+` buttons
- Turn on the lead screw using the `ON` button
- Start the lathe spindle, use `LEFT` and `RIGHT` buttons to move if needed, stop spindle when done
- Turn off the lead screw using the `ON` button

## Soft limits / automatic stops

Move the carriage using `LEFT` or `RIGHT` to the desired stop position and press `L STOP` or `R STOP` depending on which limit you'd like to set.

When both limits are set, you can:

- Use lathe forward/reverse spindle movements to move the carriage between the stops
- Use `LEFT` and `RIGHT` buttons to move the carriage within the stops

Setting only one stop is also supported. Stops aren't lost when `ON` button is clicked or pitch is changed.

## Moving the carriage

Use `LEFT` and `RIGHT` buttons to move the carriage. If stops are set, they will be respected during the movement.

When the ELS is off, carriage will move by the distance set using `Step` button but at least 1 stepper motor step.

When the ELS is ON, carriage will move in pitch increments (stay in the thread) and travel at least the distance set by `Step` button.

## Multi-start threads

Use middle button in the right-side vertical row of buttons (`Mode` button) and switch into the `MUL` mode. Use `+` and `-` buttons to increase/decrease the number of starts in your multi-start thread.

Set left and right limits. Cut thread normally and use `LEFT` or `RIGHT` buttons to move the carriage between cuts (no need to turn off the spindle). Controller automatically moves to the next start of the thread when a limit is reached.

## Asynchronous mode

Click `Mode` button until you enter the `ASY` mode. In this mode the spindle rotation is ignored and motor moves with a constant speed of 1 pitch per second when ELS is `ON`. Limits and manual movement works normally.

## Losing the thread

The spindle and stepper positions are reset to 0 `ON`, `-` or `+` buttons are pressed.

## Out-of-sync situations

It's possible for the lead screw to go out of sync with the spindle by removing the `L STOP` or `R STOP` while the carriage is standing on it. It's indicated by the `SYN` word on the display.

This situation should resolve itself once the spindle makes a full turn.

## Resetting ELS and viewing the software version

ELS remembers all the positions and ON/OFF status when powered off. Hold `ON` button for 5+ seconds to:

  - Reset stepper and spindle positions to 0
  - Resets pitch to 0
  - Removes stops
  - Removes out-of-sync state
  - Shows NanoEls version

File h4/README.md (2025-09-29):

# NanoEls H4

4-axis Electronic Lead Screw (ELS) based on ESP32-S3 for metal lathes.

h4-600px

Controller is no longer available for purchase on https://kachurovskiy.com/ but you can DIY with the hardware design files provided.

## Features

- Metric, inch and TPI support, cut any thread with utmost precision
- Controls 2 axes - lead screw (Z) and cross-slide (X)
- Manual movement of both axes: by eye, in precise steps or by a precise amount
- Disabling/enabling of stepper motors allowing to switch to manual operations in 1 click
- Soft limits allowing to cut e.g. close to the chuck
- Automatic threads: just set length, depth, pitch and number of passes
- Automatic multi-pass turning and facing
- Automatic multi-start threads
- Automatic half-spheres and ellipses
- Cone mode to cut internal or external tapers
- Cut-off mode allowing for smooth in-feed
- RPM and angle indication
- Internal/external and left-to-right versions of each automatic operation
- Backlash compensation
- Rotary encoders to move axes
- Rotary or linear 3rd axis

Advanced CNC features via [lathecode online CAD](https://github.com/kachurovskiy/lathecode):

- Running GCode over USB
- Saving GCode to device to run later

## Hardware

[Datasheet PDF](https://raw.githubusercontent.com/kachurovskiy/nanoels/main/h4/h4.pdf) contains schematic, screen, terminals and other hardware details that aren't specific do the electronic lead screw application.

See [parts.md](https://github.com/kachurovskiy/nanoels/blob/main/h4/parts.md) for Gerber, BOM, STL and other info required for DIY assembly.

See [hardware.md](https://github.com/kachurovskiy/nanoels/blob/main/hardware.md) for mounts and adapters for encoders and motors. For attaching a cross-slide motor, consider [belt-based](https://www.thingiverse.com/thing:6058899) or [gear-based](https://www.thingiverse.com/thing:4714722) NEMA 17 mounts.

## Wiring

h4-back-cropped

Encoder terminal:

- GND - connect to encoder power-in line (usually black) and wire shielding if there's any
- 5V - connect to encoder power-in line (usually red)
- ENCB - connect to one of the encoder signal lines
- ENCA - connect to one of the encoder signal lines

Z axis - stepper terminal for the main lead screw:

- 5V - connect to stepper driver PUL+, DIR+, ENA+ and wire shielding if there's any
- ENA - connect to stepper driver ENA-
- DIR - connect to stepper driver DIR-
- STEP - connect to stepper driver PUL-

X axis - stepper terminal for the cross-slide:

- 5V - connect to stepper driver PUL+, DIR+, ENA+ and wire shielding if there's any
- ENA - connect to stepper driver ENA-
- DIR - connect to stepper driver DIR-
- STEP - connect to stepper driver PUL-

Note: depending on your particular encoder, stepper driver and signal wire, H4 might not be able to provide sufficient voltage/current on the 5V output lines above due to the presence of a fuse and current-limiting resistors on the PCB. If your encoder isn't functioning or steppers are working erratically, consider supplying 5V from an external power source to the 5V lines above.

## Programming the controller

- Install the [Arduino IDE](https://docs.arduino.cc/software/ide-v2)
- Add `https://raw.githubusercontent.com/espressif/arduino-esp32/gh-pages/package_esp32_index.json` in [Preferences as "Additional board manager URLs"](https://github.com/kachurovskiy/nanoels/assets/517919/dcc023e6-20fc-4284-ba56-d466dbe4ce53)
- Install `esp32` [via Board Manager](https://github.com/kachurovskiy/nanoels/assets/517919/094d00ff-1e51-4f26-bb81-aa4ad42bde2a)
- Install Adafruit `TCA8418` library [via Library Manager](https://github.com/kachurovskiy/nanoels/assets/517919/90326e0d-6600-4b47-aa66-1177c4b9cc27)
- Download [this repository](https://github.com/kachurovskiy/nanoels/archive/refs/heads/main.zip), unzip, go to `h4` directory and open `h4.ino` file in the Arduino IDE
- Check the top constants (e.g. encoder steps, motor steps, display offset) and adjust if needed
- Select "ESP32S3 Dev Module" as device at the top, pick COM port that appears when you connect the device with a USB cable
- Upload the sketch to your H4 controller

A few things to check after upload:

- Spindle direction: show angle on screen using IconDisplay. Rotate the chuck forward manually - angle should increase. If it decreases, swap `ENCB` and `ENCA` wires in the terminal
- Motor direction: try IconArrowLeft IconArrowRight IconArrowUp IconArrowDown buttons - if motor is moving in the wrong direction, change `INVERT_Z` or `INVERT_X` in the code, re-upload the sketch (or swap the motor leads `A+` and `A-` in the stepper driver)

Troubleshooting:

- Arduino IDE doesn't detect NanoEls H4: try a different USB cable
- Not sure which COM port is NanoEls H4: unplug it, check the list of available ports in Arduino IDE, plug H4 in, see new port that appeared is H4
- `ImportError: No module named serial` error on Linux: try `sudo apt install python3-serial`

## Usage manual

**This manual corresponds to `NanoEls H4 V12`. To see your software version, hold IconStop for 5 seconds. If you have a different version - e.g. `V5`, please update to the latest one.**

### Switching between metric and imperial

Press IconMeasure to change the system of measurement between:

- Metric (mm)
- Inch
- TPI

It affects how the pitch and position is displayed and changes, move steps for precision moves.

### Setting pitch

https://github.com/kachurovskiy/nanoels/assets/517919/58da0f90-8adc-4035-a18c-198c88a73c22

Pitch is the distance that carriage will move when the spindle makes the full turn. For example, M14 thread uses 2mm pitch.

Use numpad buttons Icon0 to Icon9 to enter the pitch value. For example, pressing Icon1 Icon5 Icon0 followed by IconPlay will set the pitch to `0.15mm`, `0.15"` or `150tpi` depending on the current measurement system.

Adjust the desired pitch using IconMinus and IconPlus buttons.

Use negative pitch values e.g. `-2mm` to cut left-to-right threads. To change the pitch sign, press IconReverse.

### Setting step

https://github.com/kachurovskiy/nanoels/assets/517919/c31d04b4-958b-48af-9717-09322885c12c

Step setting is used for manual carriage moves in `off` state - i.e. when no mode is active and no thread is being cut. Current step setting is normally shown on the 1st screen line as e.g. `step 1mm` or `step 0.1"` but can be hidden if there's no space.

Pressing IconSteps cycles through the list of predefined steps:

- Metric: `1mm`, `0.1mm`, `0.01mm`
- Imperial: `0.1"`, `0.01"`, `0.001"`

Use numpad buttons Icon0 to Icon9 to enter a custom step value. Pressing IconSteps when the screen bottom line shows `Use 1.234mm?` will make the step equal to `1.234mm`.

### Zeroing the axes

Z and X position can be counted from any location you'd like. By pressing IconZ or IconX you can take the current position on the respective axis as `0`.

You can also set the `0` at a position ahead of the current position by entering the required distance using the numpad buttons Icon0 to Icon9 and then pressing IconZ or IconX.

You can set X0 on the lathe centerline by making a light cut, measuring diameter, entering it on the numpad and then pressing IconA.

### Moving left and right, in and out

https://github.com/kachurovskiy/nanoels/assets/517919/6b6dfb87-ee3a-4e2c-b272-3af0c08e09fa

Press IconArrowLeft and IconArrowRight buttons to move the carriage, IconArrowUp and IconArrowDown to move the cross-slide.

Depending on the state of the controller, pressing the move button will result in traveling the following distance:

- `off` - carriage will move by the step distance but at least 1 stepper motor step
- `ON` - carriage will move in pitch increments (stay in the thread) but at least the step distance

If step is set to `1mm` or `0.1"`, pressing and holding move buttons results in continuous movement allowing for quick tool positioning. If step is set to values other than `1mm` or `0.1"`, there's a short delay betwen steps when manual moves are triggered allowing to precisely position the tool.

Changing direction will result in automatic backlash compensation, for example with backlash `0.65mm` and step `0.1mm`, first move in the opposite direction will result in lead screw turning `0.75mm`. Tool should still only move `0.1mm` assuming backlash is uniform and is specified correclty.

When `off`, use numpad buttons Icon0 to Icon9 to enter a custom move distance. Pressing a move button when the screen bottom line shows `Use 1.234mm?` will move `1.234mm` in the corresponding direction. If there's an automatic stop limiting travel, it will move up to the limit and beep.

### Soft limits / automatic stops

https://github.com/kachurovskiy/nanoels/assets/517919/8b29bba1-941e-4e69-8598-6cb8aa0c6929

Soft limits allow to cut close to the lathe chuck, part shoulder or rear support without hitting them.

One way to set a soft limit is to move the carriage or cross-slide to the desired position and press one of the IconLimitLeft IconLimitRight IconLimitUp IconLimitDown limit buttons. Pressing the button again removes the limit regardless of the current position.

Another way to set a soft limit is to use numpad buttons Icon0 to Icon9 to enter a distance relative to the current position. Pressing a limit button when the screen bottom line shows `Use 1.234mm?` will set corresponding limit `1.234mm` away from the current position.

Soft limits are used when preparing an automatic operation like turning, facing, threading and cutting off.

### Gearbox mode / electronic lead screw

https://github.com/kachurovskiy/nanoels/assets/517919/df9fa150-0284-4aec-ab81-8e37f4a747bc

Press IconGears to switch to the gearbox mode. After turning the controller `ON` with the IconPlay button, lead screw will move the distance of 1 pitch for 1 spindle turn.

With a small pitch like `0.07mm` this mode is useful for turning - gradually taking off material from the outer diameter of the part.

With a large pitch like `0.5"` one can cut a corresponding thread. Moving with IconArrowLeft and IconArrowRight buttons is supported and does not result in losing the thread.

Direction of movement can be quickly reversed with IconReverse button which toggles the pitch sign. Negative pitch can also be used to cut left threads.

Soft limits are respected in this mode allowing to finish the cut in a precise position.

Cross-slide can be moved with manual move buttons or disabled using IconA and be operated manually.

Press IconStop to turn gearbox mode `off` and decouple lead screw movements from spindle turns.

### Automatic turning

https://github.com/kachurovskiy/nanoels/assets/517919/30d98d1e-6ddc-4f40-b637-48f76003cd33

Press IconTurning to switch to the automatic turning mode which is usually used to take large amount of material from the inside or outside diameter of the part in multiple passes.

Set the desired pitch to a suitable value e.g. `0.05mm`. Negative pitch will make turning start from the left limit, positive pitch will make it start from the right. All soft limits (left, right, up, down) must be set before the operation can be started.

Pressing IconPlay guides through remaining steps:

- Entering the numer of passes - use numpad or IconPlus and IconMinus, confirm with IconPlay
- Selecting `External` or `Internal` operation - use IconArrowLeft and IconArrowRight to change selection. Internal operations start from the IconLimitUp limit, external from the IconLimitDown limit. Confirm with IconPlay
- Confirm the final `Go?` question with IconPlay

Turn on the spindle. Operation will proceed fully automatically and the cutter will return to the starting position when done. Pitch can be adjusted on the fly using IconPlus and IconMinus.

You can skip to the next pass using IconPlay while the operation is running.

Operation can be stopped at any time by pressing IconStop or using manual move buttons.

### Automatic facing

Press IconFacing to switch to the automatic facing mode which is usually used to take large amount of material from the face of the part in 1 or more passes.

It's setup in the same way as automatic turning above. When running, passes are made along the face instead of the side of the part. Negative pitch will make facing start from the inside.

### Cone

https://github.com/kachurovskiy/nanoels/assets/517919/6dd4a5e6-12ef-45a5-a24e-4a538f206546

Press IconCone to switch to the cone mode which maintains a constant ratio of movement between the X and Z axes. Cone mode doesn't require soft limits to be set but if they are set, they are respected.

Pressing IconPlay guides through the setup:

- Enter cone ratio which is calculated as `(major_diameter - minor_diameter) / length`, see [this spreadsheet for most used values](https://docs.google.com/spreadsheets/d/1l0FUMtlWUjPywN9j94DOL84lB8dFrvdRWZIffT2NoHA/edit?usp=sharing). Confirm with IconPlay
- Select `External` or `Internal` cone - use IconArrowLeft and IconArrowRight to change selection. Confirm with IconPlay

Turn on the spindle. Pitch can be adjusted on the fly using IconPlus and IconMinus. It's convenient to cut multiple cone passes with IconReverse moving the tool in using manual move buttons.

### Automatic cut-off

https://github.com/kachurovskiy/nanoels/assets/517919/fe5245b8-4bf4-4001-8762-c786e85a2369

Press IconParting to switch to the automatic parting mode which gradually feeds the cross-slide into the part from outside or inside in one or multiple passes.

Set the desired pitch to a suitable value e.g. `0.05mm`. Negative pitch will make turning start from the inside, positive pitch will make it start from the outside. IconArrowUp and IconLimitDown soft limits must be set before the operation can be started.

Pressing IconPlay guides through remaining steps:

- Entering the numer of passes - use numpad or IconPlus and IconMinus, confirm with IconPlay
- Check that pitch corresponds to the desired direction of cutting, click IconReverse to change it
- Confirm the final `Go?` question with IconPlay

Turn on the spindle. Operation will proceed fully automatically and the cutter will return to the starting position when done. Pitch can be adjusted on the fly using IconPlus and IconMinus.

Operation can be stopped at any time by pressing IconStop or using manual move buttons.

### Automatic threading

Press IconThread to switch to the automatic threading which will cut a thread (optionally multi-start one) in multiple passes.

Set the desired pitch to a suitable value e.g. `2mm` or `20tpi`. Negative pitch will result in a left thread and will make the operation start from the left limit, positive pitch will make the operation start from the right. All soft limits (left, right, up, down) must be set before the operation can be started.

Pressing IconPlay guides through remaining steps:

- Entering the numer of passes - use numpad or IconPlus and IconMinus, confirm with IconPlay
- Selecting `External` or `Internal` operation - use IconArrowLeft and IconArrowRight to change selection. Internal operations start from the IconLimitUp limit, external from the IconLimitDown limit. For multi-start thread, press IconPlus to add more starts. Confirm with IconPlay
- Confirm the final `Go?` question with IconPlay

Turn on the spindle. Operation will proceed fully automatically and the cutter will return to the starting position when done.

You can skip to the next pass using IconPlay while the operation is running.

Operation can be stopped at any time by pressing IconStop or using manual move buttons.

### Automatic half-spheres and half-ellipses

Press IconM several times until `ELLI` is shown on screen. In this mode, cutter will form convex or concave half-ellipses in multiple passes.

Starting operation with positive pitch forms left hemisphere, with negative pitch - right hemisphere. This ensures that X backlash doesn't affect the cut.

`External` mode forms convex hemisphere (curved outward), `Internal` forms concave hemisphere (curved inward). Start and end points are the same in both cases.

Set the desired pitch to a suitable value e.g. `0.07mm`. All soft limits (left, right, up, down) must be set before the operation can be started.

Pressing IconPlay guides through remaining steps:

- Entering the numer of passes - use numpad or IconPlus and IconMinus, confirm with IconPlay
- Selecting `External` or `Internal` operation - use IconArrowLeft and IconArrowRight to change selection. Confirm with IconPlay
- Confirm the final `Go?` question with IconPlay

Turn on the spindle. Operation will proceed fully automatically and the cutter will return to the starting position when done. Adjusting the pitch on the fly is not supported.

Operation can be stopped at any time by pressing IconStop or using manual move buttons.

### Async mode

In this mode the carriage disregards spindle movements and instead moves with constant speed of `pitch` per second. When pitch is positive, `Z` axis moves to the left. When pitch is negative, `Z` axis moves to the right. If pitch is 0, `Z` axis doesn't move.

You can adjust the pitch using IconMinus or IconPlus to adjust the movement speed.

Async mode respects limits if they are set.

### GCode



**WARNING:** GCode mode ignores automatic stops. Use IconStop or emergency stop. Clicking `Stop` in the Web UI has a delay.

This mode allows to control tool movement from the PC. Programs can be generated automatically using textual part description - see [lathecode README](https://github.com/kachurovskiy/lathecode) for more info.

Before the program runs, it's critical to zero the tool:

- Set `Z=0` at the point where the left edge of the cutting tool touches the right face of the stock - e.g. by taking a light facing cut and pressing IconZ
- Set `X=0` at the point where the front edge of the cutting tool is on the centerline - e.g. take of a small amount of material from the outside diameter, enter the measured diameter using the numpad, press IconA

Before cutting your first part, zero the tool "in the air" and check that your program is doing what you expect.

Use [**lathecode online editor**](https://kachurovskiy.com/lathecode/) to define your part and run or save the GCode program to H4.

#### Saved programs

Switch to `GCODE` mode and press IconPlay.

Use IconArrowUp and IconArrowDown to select the program, IconMinus to delete the program, IconPlay to run it.

#### Technical details of the GCode mode

This section is intended for the few people sending raw serial commands to H4 - not for regular lathecode users.

Commands can be sent to device e.g. using [our Web-based GCode sender](https://kachurovskiy.github.io/nanoels/h4/sender.html) while connected over USB. The following commands are currently implemented:

- G0, G1 - linear move
- G20, G21 - inch or metric mode
- F - setting feed as mm/min or inch/min
- X, Z - single axis move
- G90, G91 - absolute or relative positioning
- G18 - ZX plane

Sample command `G1 X5 Z2 F100` will move the cutter to X=5mm, Z=2mm at 100 mm/sec in absolute metric mode.

To save a program `X0\n\Z10` under a name `Part1`, send `"Part1\nX0\n\Z10"`. To remove it, send `"Part1"`. To remove all saved programs, send `""`.

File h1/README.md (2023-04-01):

**This software and instructions are provided as is, without warranty of any kind. This is a hobby project. Using this might damage your equipment, cause injury or death. Use at your own risk.**

# NanoEls H1

**This page is provided for people who have already built or have already started building H1 version of the ELS. If you're just starting, use the new and improved [H2 version](https://github.com/kachurovskiy/nanoels/tree/main/h2).**

Cheap DIY Electronic Lead Screw (ELS) based on Arduino Nano for metal lathes.

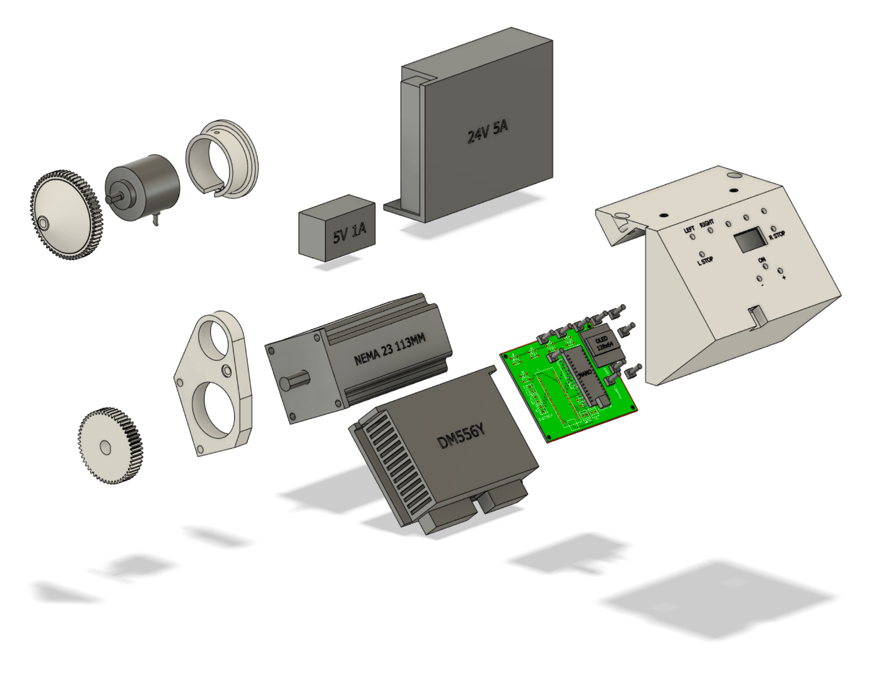
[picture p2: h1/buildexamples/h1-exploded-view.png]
NanoEls explosion diagram


# Features

- Positive and negative screw pitches
  - From -10mm to 10mm
  - Resolution 0.01mm
- Automatic lead screw stops
- Independent carriage moves without losing the thread
- Lead screw position indication
- Spindle angle indication

# Hardware overview

- 5 plastic 3D-printed parts (gears, mounts)
- Uses readily available hardware
  - 46€ Nema 23 stepper and driver (50% more for closed loop)
  - 16€ 48V 5A power supply
  - 9€ printed curcuit board (PCB)
  - 9€ rotary encoder
  - 3€ Arduino Nano
  - 3€ push buttons
  - 2€ OLED display
  - 5V power supply e.g. an old phone charger
  - 8 bolts, 2 nuts, 2 washers and a few wires
  - Optionally, two `2kOhm` resistors
- Does not require metalworking
- Does not require drilling holes in the lathe

# Other hardware required

- Soldering iron, solder
- Hex and screwdrivers
- Soft hammer or a woodworking clamp
- 50T metal gear that your lathe came with
- Grease for the gears

# Build examples

- [bestbean](https://github.com/kachurovskiy/nanoels/discussions/109)
- [Dididu12](https://github.com/kachurovskiy/nanoels/discussions/40#discussioncomment-2019521)
- [Hedning003](https://github.com/kachurovskiy/nanoels/discussions/16)
- [HW61](https://github.com/kachurovskiy/nanoels/discussions/43)
- [kachurovskiy](https://www.youtube.com/watch?v=9uTdDk2EqG4?t=272)
- [mockendon](https://github.com/kachurovskiy/nanoels/discussions/32)
- [Sonny Madlangbayan](https://www.youtube.com/watch?v=qiPQUa50Uog)
- [wberggren](https://github.com/kachurovskiy/nanoels/discussions/13)
- [WillieJilesen](https://github.com/kachurovskiy/nanoels/discussions/39)
- [zabu83](https://github.com/kachurovskiy/nanoels/discussions/11)

# Limitations

- PLA plastic gears and mounts shouldn't heat up or they will deform and disconnect. Stepper can heat up quite a bit during continuous operation. Depending on the stepper driver current, the limit seems to be ~50% duty cycle with 10min operation / 10min cooldown. For higher duty cycle something like metal HTD 5M gears, belt and a metal stepper mount would be required. Another option is using PETG or ABS.
- Nema 23 stepper usable maximum is ~600 RPM, here a 1:1 stepper to leadscrew ratio is used. In practice this means that cutting e.g. 2mm thread with a 2mm leadscrew spindle top speed should stay under 600 RPM.
  - Cheap brand-less drivers are worse at handling high RPM
  - NanoEls would take the stepper at 1000 RPM and higher but it likely won't have much torque at that point
  - This can be mitigated to some extent by using e.g. 40 tooth gear on the leadscrew and 60 tooth gear on the motor at the expense of the maximum leadsrew torque
- Lead screw position only equals the carriage position if the backlash was taken out before the measurement started. Changing the direction introduces the backlash again.

# Big display

NanoEls also supports LCD2004 displays [such as this one (4€)](https://www.aliexpress.com/item/4001135515638.html). Those are 20-char, 4-line with 5mm tall letters comparing to 2.5mm tall letters on an OLED display. Full update takes `57ms` on an LCD comparing to `46ms` on OLED. The backlight could be a bit uncofortable for the eyes, see [a visual comparison](https://imgur.com/a/TbHg9Y3).

If you're using LCD2004, uncomment the line `#define LCD`, install the library `LiquidCrystal I2C` from [Frank de Brabander](https://github.com/fdebrabander) via the Library Manager and re-upload the sketch.

# Instructions

We've tried to simplify the process as much as possible but building NanoEls is still going to take considerable time and effort, basic mechanical and electrical knowledge.

You might need to design your own mounts and gears if the ones we have don't fit. If you need help designing a 3D printed part, please open a GitHub Issue with exact dimensions of the part that you need.

## Parts

See https://github.com/kachurovskiy/nanoels/blob/main/hardware.md for encoder, motor, gearing and mounting info.

### Arduino Nano

The code was tested using an Arduino Nano V3 clone.

### OLED display

SSD1306 monochrome 4-pin I2C OLED 128x64 display. **Warning:** make sure that your OLED has legs in the following order to work on the PCB - GND VCC SCL SDA.

### Buttons

Using 6x6x13mm switches. 13mm is the optimal height for the provided case, if you're using a different case, desired height might be different. AliExpress has very convenient 200 button sets of different height for a few euros.

6x6 buttons can be too small for fingers to comfortably click, consider buying caps to put on them, keywords for AliExpress are "switch push button hat 6mm".

### 5V power supply

Arduino Nano doesn't draw much current so a 5V 0.5A phone charger would work.

### PCB

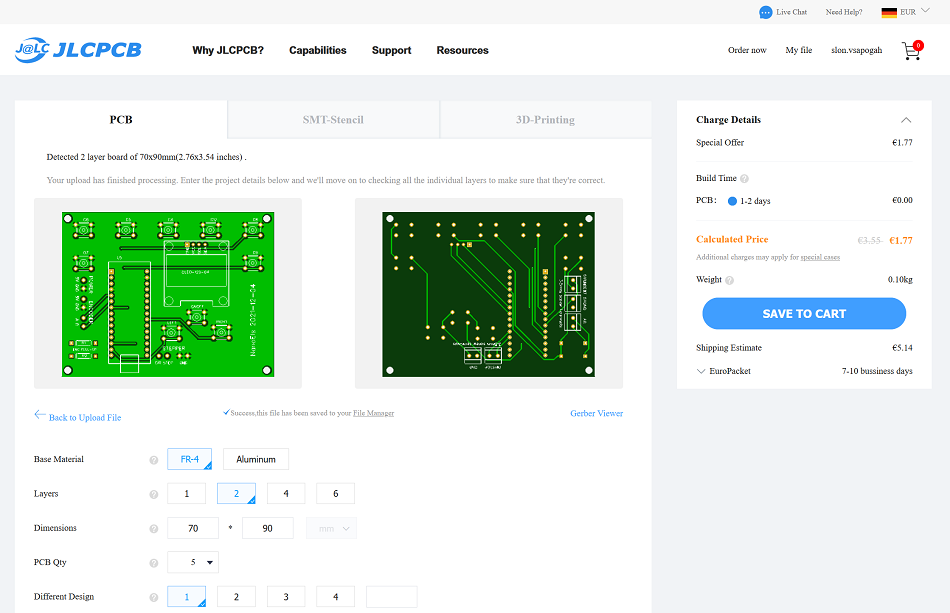
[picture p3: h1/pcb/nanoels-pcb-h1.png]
NanoEls H1 PCB


[Gerber ZIP for production](https://github.com/kachurovskiy/nanoels/blob/main/h1/pcb/nanoels-pcb-h1.zip)

It's a 70mm by 90mm board with holes for M3 mounting bolts, 1.6mm thick. You will need clearance above, below and on the sides of the board for the through-hole components, their pins (legs) and wires coming into the PCB.

PCB is best placed away from the electromagnetic noise sources such as lathe motor wires. Grounded metal housing is ideal.

**Some PCB production techniques use lead and other nasty stuff. Order at your own risk and dispose properly.**

Ordering it from JLCPCB takes just a few clicks - upload the ZIP file, use all default settings, choose shipping and checkout.

### 3D-printed parts

#### Case

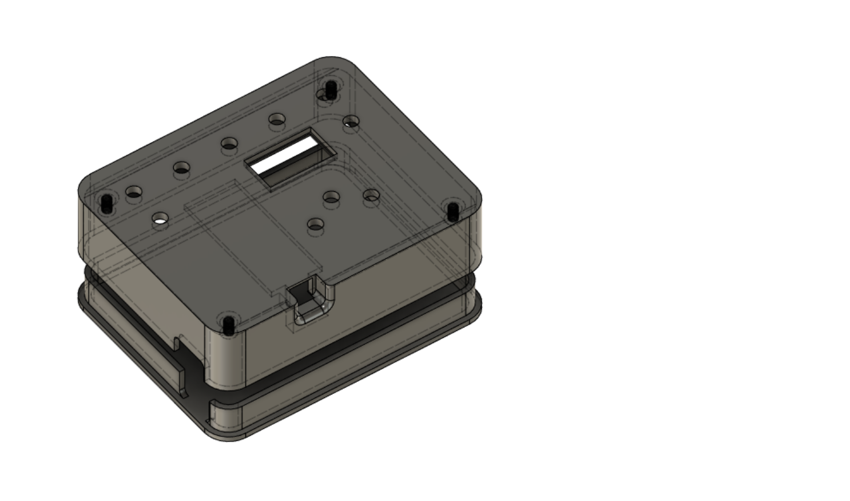
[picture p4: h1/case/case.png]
Case


[STL part 1](https://github.com/kachurovskiy/nanoels/raw/main/h1/case/nanoels-box-part1.stl) and [part 2](https://github.com/kachurovskiy/nanoels/raw/main/h1/case/nanoels-box-part2.stl)

Case size is 102x82x27mm. PCB is mounted onto the case with 4 M3 bolts.

## Assembly

**Working with electrical wiring is dangerous, unplug the lathe. Proceed at your own risk.**

Connect the 24V and 5V power supplies to the lathe power so that the lathe on/off and safety switches cut off the power for the ELS too.

Test Arduino Nano **before** soldering it on, unsoldering it without a desoldering station is very hard.

Don't solder the Arduino upside-down or rotated 180 degrees, check the white outlines on the board.

Carefully solder 10 buttons (6X6X11 switches to fit the provided case), OLED 128x64 4-pin display and an Arduino Nano onto it. Plug USB into Arduino to test - display and buttons shoulad already work.

It's important that buttons are soldered vertically or the result won't fit into a case. To achieve this, solder only 2 diagonal legs for each button first while pressing on the button firmly. Then check all buttons for verticalness, at this point it's easy to correct the angle by pressing on the button and re-heating one of the legs. Once satisfied, proceed to solder all the remaining legs. 

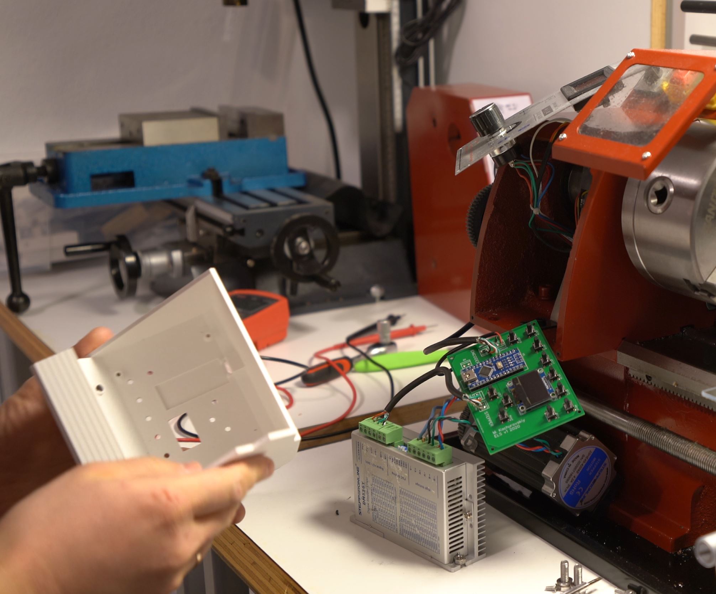
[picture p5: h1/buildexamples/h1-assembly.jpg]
Assembly


Solder 5V/GND wires to the PCB.

Solder encoder and stepper driver wires to the PCB according to the input/output labels on the PCB.

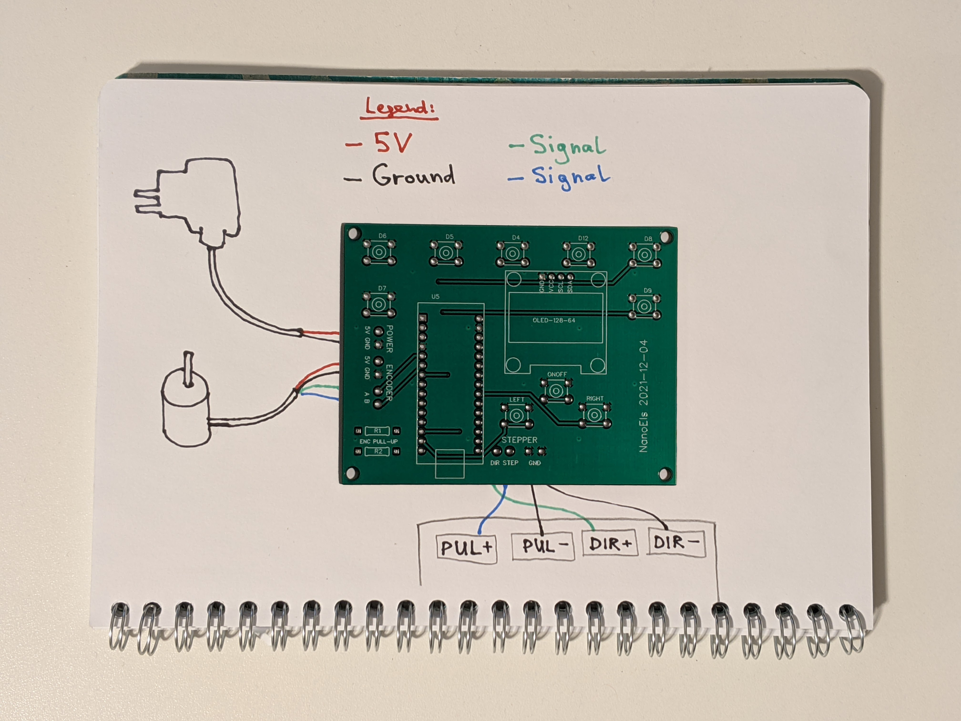
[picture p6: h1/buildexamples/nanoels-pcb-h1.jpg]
PCB wiring


**Important: there can be a metal mesh under the insulation around your wires, it's shielding, don't just cut it off. Solder it to ground (GND), together with the black ground cable.**

Screw terminals are designed to be soldered on the bottom side of the PCB.

Optinally solder two 2kOhm pull-up resistors. They aren't strictly needed but will improve the stability of the optical encoder readings.

## Programming the Arduino

- Download the Arduino IDE
- Install `Adafruit_SSD1306` and `FastGPIO` libraries via the Library Manager in the Arduino IDE
- Download and open [NanoEls.ino](https://github.com/kachurovskiy/nanoels/raw/main/h1/NanoEls.ino)
- Check the top constants (e.g. encoder steps, motor steps, display offset) and adjust if needed
- Upload the sketch to your Arduino Nano
- Swap D2 and D3 pins in the code if carriage direction is inverted, re-upload

# Operating the ELS

## Safety

- Make sure that stepper motor and ELS are turned off using the lathe emergency power off switch
- Test the automatic stop and other ELS functionality before relying on it
- **In case of unexpected movements, disengage the half-nut or use the emergency power off switch**

## Turning

- Select the desired pitch using `-` and `+` buttons or `0.10mm`, `1mm` and `2mm` shortcut buttons in the top row
- Turn on the lead screw using the `ON` button
- Start the lathe spindle
- Stop the lathe spindle when done
- Turn off the lead screw using the `ON` button

## Automatic stops

- Move the carriage with the help of ELS to the desired stop position
- Set the stop using e.g. `L STOP` button
- Hold `RIGHT` to move to another stop position and press `R STOP`

Now you can:

- Use lathe forward/reverse spindle movements to move the carriage between the stops
- Use `LEFT` and `RIGHT` buttons to move the carriage ~1mm (possibly more when required to stay on the thread) within the stops in either direction when spindle is not turning

Setting only one stop is also supported. Stops aren't lost when `ON` button is clicked or pitch is changed.

## Carriage movements

- Make sure the cutting tool is not going to contact the material and there's room to move the carriage physically
- Use `LEFT` and `RIGHT` buttons to move the carriage ~1mm (possibly more or less when required to stay on the thread) when spindle is not turning
- If stops are set, they will be respected

Using `LEFT` and `RIGHT` buttons is not supported when the spindle is turning and ELS is on.

## Losing the thread

The spindle and stepper positions are reset to 0 every time one of the following happens:

- `ON` button is pressed (including long press for reset)
- Pitch is changed e.g. by pressing `-` or `+`
- Stepper is not in the desired position when ELS is powered up
  - Results in `LTW` lost thread warning
  - Might happen if ELS was abruptly shutdown

Thread is **not** lost when ELS is simply powered off.

## Out-of-sync situations

It's possible for the lead screw to go out of sync with the spindle by removing the `L STOP` or `R STOP` while the carriage is standing on it. It's indicated by the `SYN` word on the display.

This situation should resolve itself once the spindle makes a full turn.

## Resetting ELS and viewing the software version

ELS remembers all the positions and ON/OFF status when powered off.

- Hold `ON` button for 6 seconds
  - Reset stepper and spindle positions to 0
  - Resets pitch to 0
  - Removes stops
  - Removes out-of-sync state
  - Shows NanoEls version

# Troubleshooting

## My stepper is skipping steps

1. Check that `ENCODER_STEPS`, `MOTOR_STEPS` and `LEAD_SCREW_HMM` parameters you used match your hardware. E.g. if you tell ELS that `MOTOR_STEPS` is 400 but your actual driver is set to 200, ELS will try to move the stepper too fast and it will stall.
2. Check the mechanical connection between the stepper and the lead screw, try rotating the stepper by hand when lathe is OFF. It shouldn't be too hard to turn. If you're using gears, ensure they're turning freely, not jamming and have a tiny bit of backlash. If you're using a belt, make sure it's not overtightened.
3. Try using higher voltage, within limits of your stepper and driver. For NEMA 23, best performance is achieved at 48V but the driver has to support it.
4. Try increasing the current on your driver, within the limits of your stepper.
5. If you have a cheap brand-less driver, consider getting a higher quality driver.
6. For an immediate fix, change the acceleration (line 23) PULSE_DELTA_US from `7` to `2`, PULSE_MIN_US (line 21) from `500` to e.g. `700`.
7. Consider using a sufficently strong closed-loop stepper instead. I didn't try them myself but there are some high-rated closed loop stepper-driver sets on AliExpress for 69€.

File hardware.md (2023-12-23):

**This software and instructions are provided as is, without warranty of any kind. This is a hobby project. Using this might damage your equipment, cause injury or death. Use at your own risk.**

# Mechanical part of the ELS



Any electronic lead screw requires connecting an encoder to the lathe spindle and motor to the leadscrew.
This page provides some general guidance but every lathe is different, start a new [discussion](https://github.com/kachurovskiy/nanoels/discussions) if you have questions.

# Encoder

Tested with the [following 600 steps encoder](https://www.aliexpress.com/item/4001142743940.html). They are available on eBay/AliExpress as "optical rotary encoder".

## Encoder base

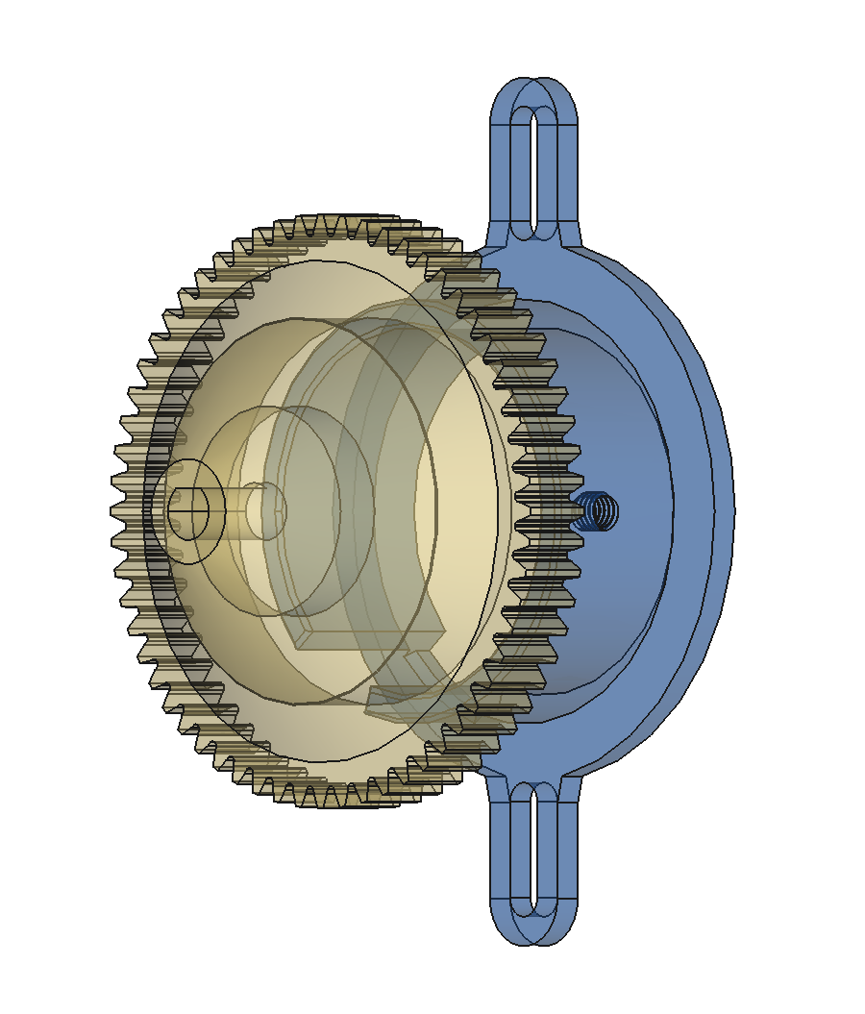
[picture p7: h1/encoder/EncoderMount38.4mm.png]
Encoder base


[STEP file for 3D printing](https://github.com/kachurovskiy/nanoels/raw/main/h1/encoder/EncoderMount38.4mm-Body.step)

Attached using 2x M4 bolts to the side of the headstock. Using an M4 set screw is optional.

Alternative encoder base allowing for a thicker cable: https://www.thingiverse.com/thing:5156081

## Encoder gear

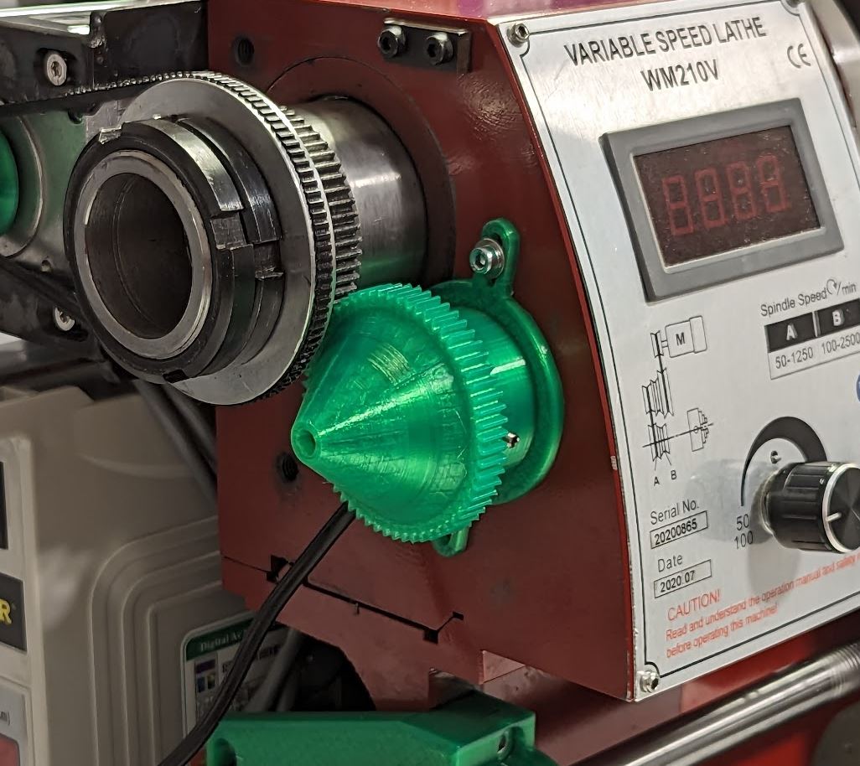
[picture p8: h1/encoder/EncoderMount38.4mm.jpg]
Encoder gear


[60 teeth gear STEP file](https://github.com/kachurovskiy/nanoels/raw/main/h1/encoder/EncoderMount38.4mm-Wheel.step)

Check the distance between the spindle gear and the lathe housing: for the provided conical gear to fit, it has to be 23mm.

Encoder gear should fit loosely to the spindle allowing for it to move ~1 degree back and forth when the spindle is idle - it reduces the noise and forces applied to the encoder.

For spindles with 56 teeth, try [56 teeth gear model by kingjamez](https://www.thingiverse.com/thing:4754021).

# Stepper and driver

Cheap drivers like TB6600 are not recommended, they are very rough and noisy.

For H1 or H2 controllers it's suggested to buy the stepper that supports 200 steps mode. Microstepping will lower maximum usable rpm 2x for each microstep increase. I can recommend STEPPERONLINE steppers for good price and performance and their drivers usually support 200 step mode.

For H4 controller it's suggested to use [integrated closed loop motors like these](https://www.aliexpress.com/item/1005005598264428.html). They don't support 200 steps mode but H4 can easily run them at 800 steps per revolution. They don't need a separate driver, don't heat up and work quetly. They do take a but more space than open-loop steppers though.

## Stepper power supply

48V power supply is used on NEMA 23 for maximum power (check your driver max voltage) but 24V might also work for light turning. Closed loop motors require less current than open loop ones since they adjust to the load. For a lathe like WM210 with NEMA 23 and NEMA 17, 4A power supply would be sufficient.

## Stepper mount

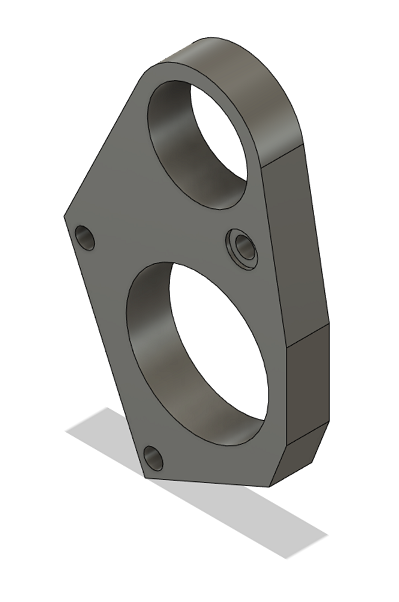
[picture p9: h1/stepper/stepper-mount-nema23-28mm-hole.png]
Stepper mount


[STL file](https://github.com/kachurovskiy/nanoels/raw/main/h1/stepper/stepper-mount-nema23-28mm-hole.stl)

Dimensions of the lead screw front bearing housing for the provided 3D-printed part to fit: 28mm outside diameter, 12mm wide.

Stepper should rest on e.g. a piece of rubber when attached to the lathe - provided 3D printed part is only held by friction and is not designed to hold the full weight of the stepper long term.

A rock-solid but more expensive (35€) option is to order a 10mm steel laser cut out stepper mount: https://imgur.com/a/exO5Atl

It's also possible to cut out the stepper mount manually from plywood: https://imgur.com/a/CSmeSm2 ([PDF](https://github.com/kachurovskiy/nanoels/raw/main/h1/stepper/nema23-mount-plywood.pdf))

Alternative stepper mount with a pinch bolt: https://www.thingiverse.com/thing:5156087

## Cross-slide mount

See https://www.thingiverse.com/thing:6058899 - I use it with a 60mm open-loop NEMA 17 motor. It fits most desktop lathes like WM210.

It's good to insert a thin metal shim in the back to thermally sink the motor in to the lathe apron. Thickness of the shim can vary.

## Stepper to leadscrew

When connecting the gears, make sure to leave ~0.5mm space between them for optimal threading. This can be achieved e.g. by temporarily placing a piece of paper between them. Add grease and spread it between the gear teeth, remove the excess.

### Option 1: plastic gear

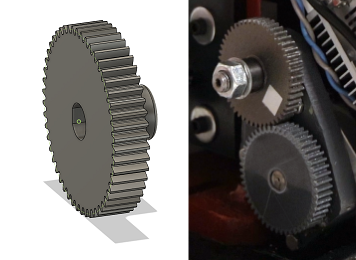
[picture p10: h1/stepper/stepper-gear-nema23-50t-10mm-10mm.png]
Stepper gear


[STL file](https://github.com/kachurovskiy/nanoels/raw/main/h1/stepper/stepper-gear-nema23-50t-10mm-10mm.stl)

This gear is designed to fit the NEMA 23 shaft (10mm diameter / 9.5mm narrow dimension) without any set screws. Gear is 10mm wide, entire part is 20mm wide.

Using this gear can be very noisy on certain RPMs.

### Option 2: adapter for the lathe gear

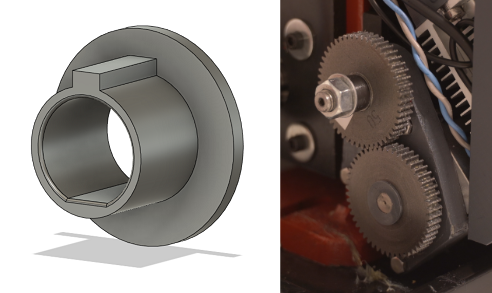
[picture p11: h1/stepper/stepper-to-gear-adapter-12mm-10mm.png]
Stepper gear adapter


[STL file](https://github.com/kachurovskiy/nanoels/raw/main/h1/stepper/stepper-to-gear-adapter-12mm-10mm.stl)

If you have 2 metal gears that add up to 100 tooth together (e.g. 2x50 tooth gears) that came with the lathe, it's possible to simply use one of them on the leadscrew and one on the stepper with the help of the adapter above. It can be somewhat noisy on certain RPMs but otherwise works well.

### Option 3: HTD 5M belt connection

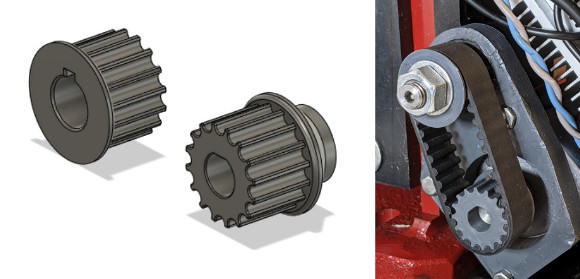
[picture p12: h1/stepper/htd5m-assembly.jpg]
Stepper HTD 5M pulleys


[STL pulley 8mm bore](https://github.com/kachurovskiy/nanoels/raw/main/h1/stepper/htd5m-16t-8b.stl)

[STL pulley 10mm bore](https://github.com/kachurovskiy/nanoels/raw/main/h1/stepper/htd5m-16t-10b.stl)

[STL pulley 12mm bore](https://github.com/kachurovskiy/nanoels/raw/main/h1/stepper/htd5m-16t-12b.stl)

This is the best stepper to leadscrew connection method that I tried so far but it requires printing 2 parts above and buying a 180mm HTD 5M belt which is not expensive (2-10€) but can be hard to find.

This is the quietest option that also doesn't need greasing. 2 pulleys and a belt fit tight on the normal stepper mount shown above without a need for a tensioner.

16T-5M pulleys with various inner bore diameters are also available on AliExpress for 5-6€ each.

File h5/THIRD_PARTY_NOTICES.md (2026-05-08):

## Firmware binary licenses

Precompiled `h5.ino.YYYYMMDD.bin` firmware files are built from NanoEls source in this repository under the [MIT License](../LICENSE). They also include statically linked third-party components from the Arduino/ESP32 toolchain and Arduino libraries.

- [Arduino core for ESP32](https://github.com/espressif/arduino-esp32), licensed under [LGPL-2.1](https://www.gnu.org/licenses/old-licenses/lgpl-2.1.html)
- [WebSockets](https://github.com/Links2004/arduinoWebSockets), licensed under [LGPL-2.1](https://github.com/Links2004/arduinoWebSockets/blob/master/LICENSE)
- [PS2KeyAdvanced](https://github.com/techpaul/PS2KeyAdvanced), licensed under [LGPL-2.1](https://github.com/techpaul/PS2KeyAdvanced/blob/master/LICENSE)
- ESP-IDF components bundled with Arduino-ESP32, mostly under [Apache-2.0](https://www.apache.org/licenses/LICENSE-2.0) and other compatible open-source licenses

The firmware can be rebuilt and relinked by following [Self-compile firmware with Arduino IDE](README.md#self-compile-firmware-with-arduino-ide). If a published build uses modified third-party libraries, publish those modified sources with the binary.

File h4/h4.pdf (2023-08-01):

kachurovskiy.com | KANH4 | 2023-08-01

# 4-axis motor controller

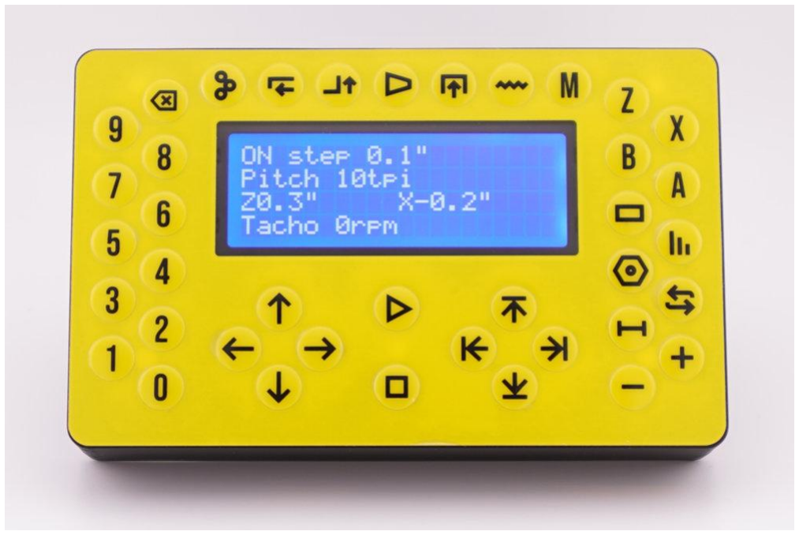
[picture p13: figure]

Based on ESP32-S3-WROOM-1U-N16R2 module, (https://www.espressif.com/sites/default/files/documentation/esp32-s3-wroom-1_wroom-1u_datasheet_en.pdf) this controler is designed to be used for home and light industrial automation and control:

- automation of lathes processing metal or plastic parts
- automation of desktop CNC routers and milling machines
- similar applications to control actuators based on digital I/O and user input

# Safety

If controller is used as a part of machinery, ensure that resulting machine complies with all applicable laws and regulations. Controller is not a safety device. Do not use the controller if it's damaged or is not working normally. Unplug all connections before disassembly, protect internal components from static electricity when disassembled.

Ensure that your emergency stop button stops all motion and it can't automatically restart when emergency stop is lifted.

# Case

Plastic case is 3D-printed from PLA. Two M5 mounting holes that are 50mm on center are located on the back side.

Two parts of the case are held together with four M3 DIN 7985 4.8 galvanized steel bolts.

# Display

Blue backlight LCD display HD44780 20x04 offers good visibility, acceptable refresh speed and viewing angles. Backlight brightness is controlled with a 1kΩ potentiometer marked "BRIGHTNESS" which is accessible when the back cover is taken off. Display contrast is controlled with the 10kΩ potentiometer tip located on the back.

# Front panel

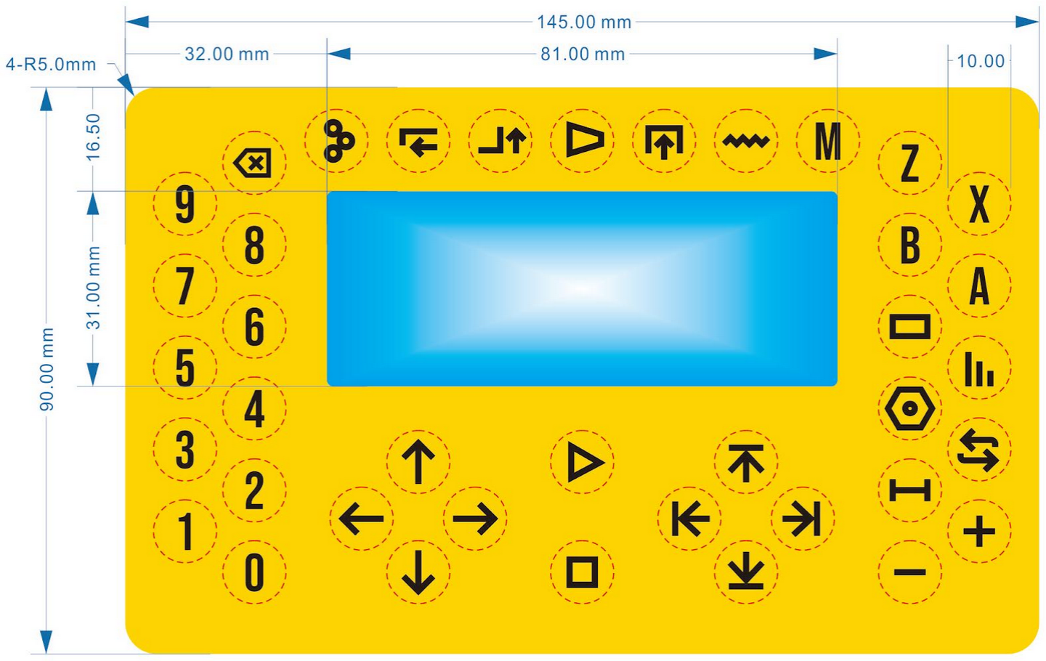
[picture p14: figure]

Front panel is made from 0.25mm polycarbonate with dimensions 145x90mm with 39 embossed buttons each 10mm in diameter. Attached with a double-sided adhesive tape, it can be replaced with a different one.

Front panel buttons are controlled with a TCA8418 chip connected to IO5 and IO6 of the ESP32-S3, see schematic below. Software libraries available for this chip making it easy to handle button events in your code.

# Power and USB

Device is powered with 5V via the USB-C port on the back protected with a 300mA holding / 600mA instantaneous current resettable fuse. USB data and power lines are connected to USB ground through ESD diodes.

# Uploading software

USB data lines are connected to the CH9102 USD-to-UART chip that is connected with RX and TX lines of the ESP32-S3. When using Arduino IDE, select "ESP32S3 Dev Module" to upload your sketch. Due to the module firmware issue (https://github.com/espressif/arduino-esp32/issues/6762) you might have to unplug USB after upload.

# Terminals

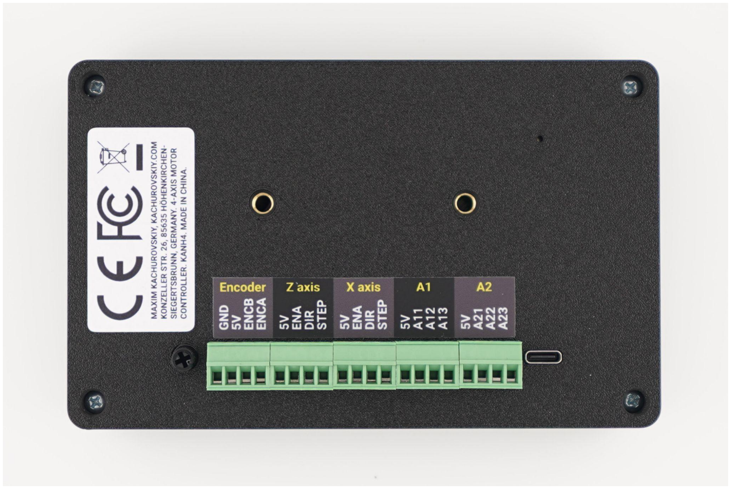
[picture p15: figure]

Pluggable screw terminals with 3.5mm pitch are located on the back side of the device. All terminals have ESD and short-circuit protection.

Group | Terminal | I/O | Description
Encoder | GND | output | Ground / neutral
| 5V | output | Encoder 5V power with resettable fuse tripping at 100mA continuous or 200mA instantaneous current at 25°C
| ENCB | in/out | 5V general purpose digital input/output line, IO7
| ENCA | in/out | 5V general purpose digital input/output line, IO15
Z axis | 5V | output | 5V signal line current-limited with a 200Ω resistor
| ENA | in/out | 5V general purpose digital input/output line, IO16
| DIR | in/out | 5V general purpose digital input/output line, IO17
| STEP | in/out | 5V general purpose digital input/output line, IO18
X axis | 5V | output | 5V signal line current-limited with a 200Ω resistor
| ENA | in/out | 5V general purpose digital input/output line, IO8
| DIR | in/out | 5V general purpose digital input/output line, IO19
| STEP | in/out | 5V general purpose digital input/output line, IO20
A1 | 5V | output | 5V signal line current-limited with a 200Ω resistor
| ENA | in/out | 5V general purpose digital input/output line, IO9
| DIR | in/out | 5V general purpose digital input/output line, IO10
| STEP | in/out | 5V general purpose digital input/output line, IO11
A2 | 5V | output | 5V signal line current-limited with a 200Ω resistor
| ENA | in/out | 5V general purpose digital input/output line, IO12
| DIR | in/out | 5V general purpose digital input/output line, IO13
| STEP | in/out | 5V general purpose digital input/output line, IO14

# Buzzer

Passive buzzer is connected to IO4 allowing the device to emit a variety of sounds.

# Main board schematic

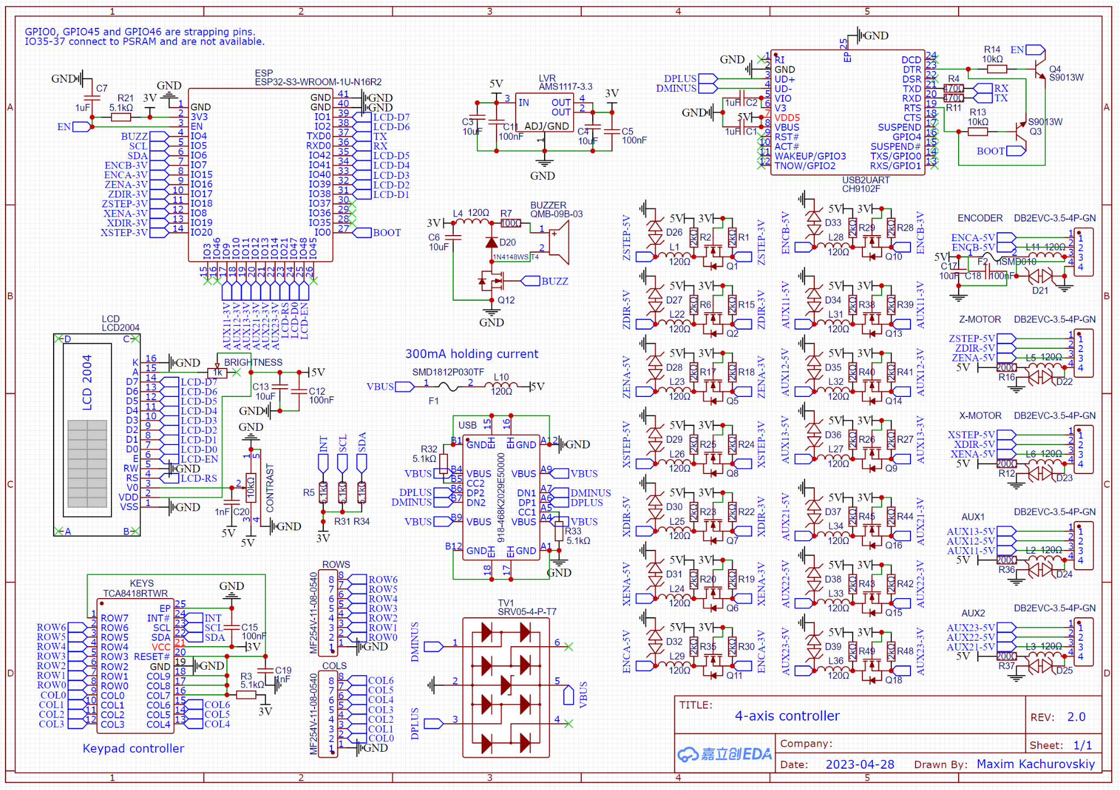
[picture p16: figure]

# Keyboard schematic

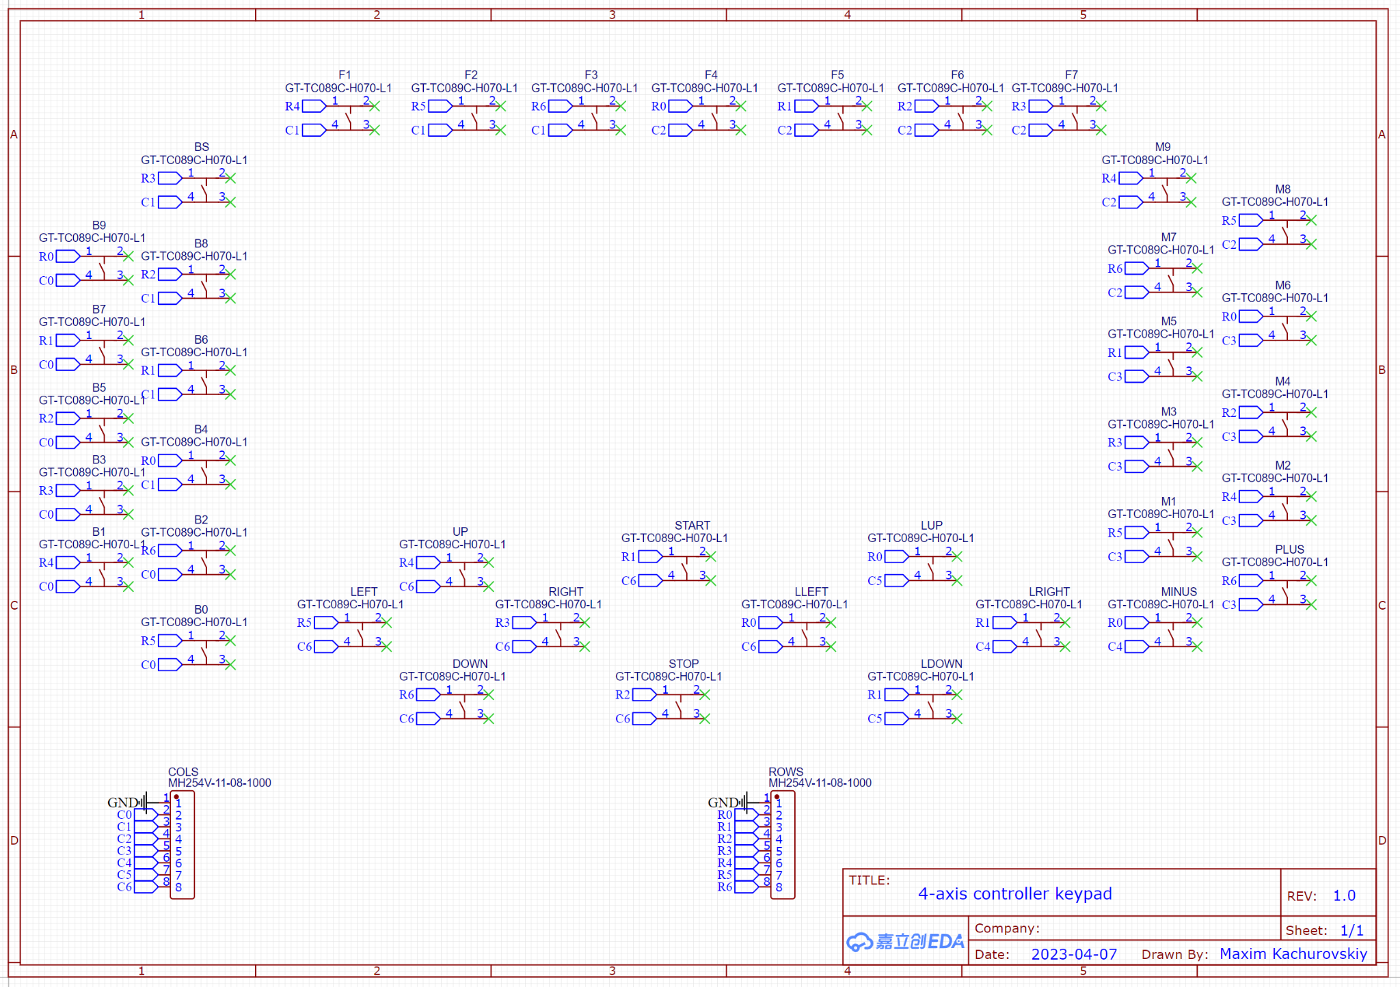
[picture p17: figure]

# Usage limits

- Not a safety device
- Use in temperatures above freezing and below 40°C, not exposed to direct sunlight
- Do not connect over 5.5V on any input, output or terminal
- Flammable

# FCC compliance

This device complies with part 15 of the FCC Rules. Operation is subject to the following two conditions: (1) This device may not cause harmful interference, and (2) this device must accept any interference received, including interference that may cause undesired operation.

This equipment has been tested and found to comply with the limits for a Class B
digital device, pursuant to part 15 of the FCC Rules. These limits are designed to provide reasonable protection against harmful interference in a residential installation. This equipment generates, uses and can radiate radio frequency energy and, if not installed and used in accordance with the instructions, may cause harmful interference to radio communications. However, there is no guarantee that interference will not occur in a particular installation. If this equipment does cause harmful interference to radio or
television reception, which can be determined by turning the equipment off and on, the user is encouraged to try to correct the interference by reorienting or relocating some of the equipment involved.

# CE compliance

This device complies with 2014/30/EU Electromagnetic compatibility (EMC), RoHS Directive 2011/65/EU and amendment Commission Delegated Directive (EU) 2015/863.

# Disposal

Don't dispose this device in the unsorted waste, please check with your municipality for electronic parts disposal options.

# Contact

With any questions, corrections or concerns please check H4 GitHub, (https://github.com/kachurovskiy/nanoels/tree/main/h4) start a new discussion there or reach out to m.kachurovskiy@gmail.com.

Maxim Kachurovskiy
Konzeller Str. 26
85635 Höhenkirchen-Siegertsbrunn
Germany

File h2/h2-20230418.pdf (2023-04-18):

kachurovskiy.com | NanoEls H2 V7 | 2023-04-18

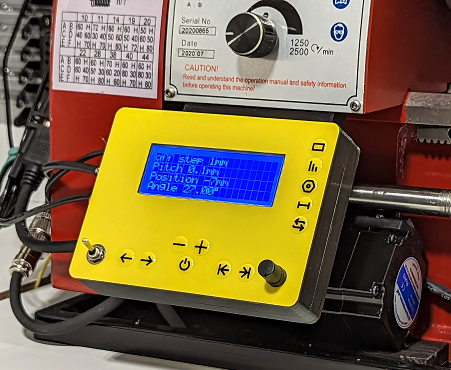
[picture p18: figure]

# Electronic lead screw

## No more greasy gear swapping!

Control your metal lathe lead screw with a few clicks.

- Set leadscrew pitch for feed or thread
- Soft limits for the carriage
- Multi-start threads in 1 start of the spindle

# Description

This electronic lead screw controller is designed for lathes processing metal or plastic parts. It is powered with 5V, controlls stepper motor that drives the lathe lead screw and receives signals from rotary encoder connected to the lathe spindle.

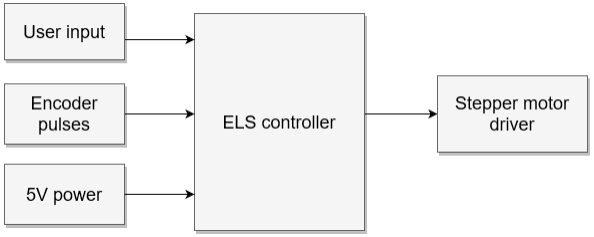
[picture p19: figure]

It's recommended to use a 600 PPR 5V A/B encoder and a 200-step stepper motor driver with a motor suitable for the cutting loads of the lathe e.g. 3 N.M. NEMA 23 for a mini lathe. Using microstepping will reduce max. stepper RPM (200 steps - 800 RPM, 800 steps - 200 RPM).

# Features

## Gearbox

Controller removes the need to use the lathe gearbox since it can drive the stepper motor with high precision according to lathe spindle rotation.

It supports metric, inch and TPI pitches (-10mm to 10mm) with resolution up to 0.001 mm/inch.

## Soft limits

Controller can limit lathe carriage movement with soft limits: just move the carriage using manual move buttons to the desired soft limit position and press the left/right limit button. Now controller won't move the motor past the given limit when e.g. cutting the thread.

## Move carriage without turning off the spindle

You can use manual move buttons without turning off the spindle and without losing the thread. With one hand holding the move button and another controlling the cross-slide, you can cut threads including multi-start ones in one go.

## Move carriage with high precision

When gearbox is on, manual move calculates the step to ensure that the tool stays in the thread.
When gearbox is on, manual move step is determined using button cycling through 1/0.1/0.01/0.001 inch or mm. Picking any value other than 1 causes the manual move to pause for a fraction of the second between steps.

## Position, angle and RPM indication

Display shows relative carriage position, spindle angle and spindle RPM. Showing angle and RPM is controlled with button. Angle is only shown when the spindle is stationary. RPM is only shown when the gearbox is off.

## Multi-start threads

Use to switch to MUL mode, select number of thread starts, set both soft limits and controller will automatically switch to the next thread when a soft limit is reached.

# Controls

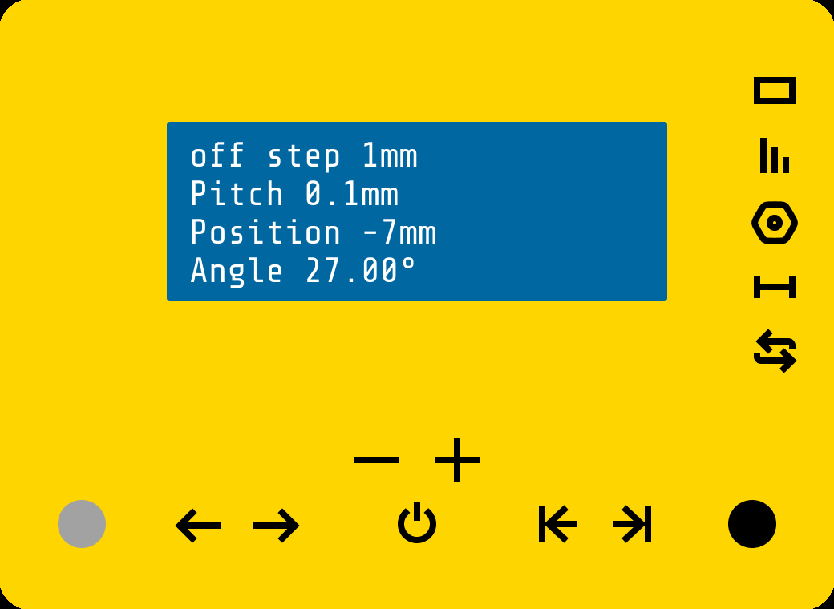
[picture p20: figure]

Icon | Function
| Power switch. Interrupts the 5V line coming from the topmost terminal. Has no effect when controller is powered via USB.
| Move the carriage to the left (increase Z position). Respects left stop (if set). Move distance depends on whether the controller is on/off. When on, will move by step distance but stay in the thread by possibly traveling a little more. When off, will move by step distance.
| Move the carriage to the right (decrease Z position). Respects right stop (if set). Move distance depends on whether the controller is on/off. When on, will move by step distance but stay in the thread by possibly traveling a little more. When off, will move by step distance.
| Decrements pitch. In mm mode: if step is 1 micron, by 1 micron - otherwise by 0.01mm, then by 0.1mm if held continuously. In inch mode: if step is 0.001", by 0.001" - otherwise by 0.01", then by 0.1" if held continuously. In TPI mode by 1 tpi.

Increments pitch. In mm mode: if step is 1 micron, by 1 micron - otherwise by 0.01mm, then by 0.1mm if held continuously. In inch mode: if step is 0.001", by 0.001" -otherwise by 0.01", then by 0.1" if held continuously. In TPI mode by 1 tpi.

Turns ELS on or off. Each press marks current position as 0 (soft limits stay in place). Continuous press for 5+ seconds resets the controller.

Sets the left soft limit at current motor position. If left limit is already set, removes it.

Sets the right soft limit at current motor position. If right limit is already set, removes it.

Adjusts screen contrast.

Inverts pitch sign e.g. changes 1mm to -1mm.

Changes measurement system between metric, inch and TPI.

Changes operating mode between gearbox, multi-start and asynchronous.

Changes manual move step.

Controls whether angle or RPM are shown on screen.

# Terminals

3.5mm pluggable screw terminals are located on the left side of the device.

Terminal | I/O | Description
5V | input | Power-in, 5V at ~100mA. Emergency Stop should interrupt power.
GND | input | Ground / neutral
ENCA | input | Lathe spindle rotary encoder quadrature signal A.
ENCB | input | Lathe spindle rotary encoder quadrature signal B.
5V | output | Lathe spindle rotary encoder power
GND | output | Lathe spindle rotary encoder ground and signal wire shielding
STEP | output | Stepper motor driver step signal, connect to PUL-
DIR | output | Stepper motor driver direction signal, connect to DIR-

ENA | output | Optional stepper motor driver enable signal, connect to ENA-
5V | output | Stepper motor driver reference voltage, connect to PUL+, DIR+, ENA+ and signal wire shielding

# Assembly

For a kit that requires soldering:

1. Connect microcontroller to your computer and test that you can upload software onto it e.g. by following instructions in the Software section
2. Disassemble the plastic case by loosening the 4 bolts on the back
3. Unscrew 2 more bolts located inside
4. Remove the PCB board from the case
5. Solder Nano microcontroller into the back side of board with long end of the legs pointing to the back side of the PCB
6. Solder the screen header pins to the screen
7. Place the screen, toggle switch and potentiometer into the front half of the case, place main PCB on top and solder them together
8. Place terminals into the back half of the case, place PCB on top and solder them together
9. Place the assembled PCB inside the case and screw everything back together

# Software

Controller USB port can be used to install controller software of your choice e.g. NanoEls H2: (https://github.com/kachurovskiy/nanoels/tree/main/h2#programming-the-arduino)

- Download the IDE (https://www.arduino.cc/en/software)
- Install LiquidCrystal and FastGPIO libraries via the Library Manager (https://docs.arduino.cc/software/ide-v1/tutorials/installing-libraries)
- Download source code, (https://github.com/kachurovskiy/nanoels/archive/refs/heads/main.zip) unzip, go to h2 directory and open h2.ino file in the IDE
- Check the top constants (e.g. encoder steps, motor steps, display offset) and adjust if needed
- Upload the sketch to your microcontroller
- Spindle direction: show angle on screen using top-right button. Rotate the chuck forward manually - angle should increment. If it decrements, either swap ENCA and ENCB wires in the terminals or swap ENC_A and ENC_B values in the code (re-upload the sketch)
- Motor direction: try LEFT and RIGHT buttons - if motor is moving in the wrong direction, change the value of INVERT_STEPPER in the code (re-upload the sketch)

# Safety

Ensure that your Emergency Stop button stops all motion and it can't automatically restart when Emergency Stop is lifted.

If controller is used as a part of machinery, ensure that resulting machine complies with all applicable laws and regulations. Controller is not a safety device. Do not use the controller if it's damaged or is not working normally.

# NanoEls H2 usage

## Switching between metric and imperial

Press to change the system of measurement between metric (mm), inch and TPI.

## Setting pitch

Pitch is the distance that carriage will move when the spindle makes the full turn. For example, M14 thread uses 2mm pitch.

Select the desired pitch using | and | buttons. If you hold the button pressed, pitch starts
changing faster after a few seconds.

Use negative pitch values e.g. -2mm to cut left-to-right threads. Do do that, you have 2 options:

- hold the | button until the pitch drops below 0 to the required value
- or press | to toggle the pitch sign between + and -

Some inch threads require setting the micron part (3rd precision point) of the pitch, to do that
click | until step is 0.001mm. Now | or | will adjust pitch by 1 micron.

## Turning or threading

1. Set desired feed/pitch using | or | buttons
2. Turn on the lead screw using
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

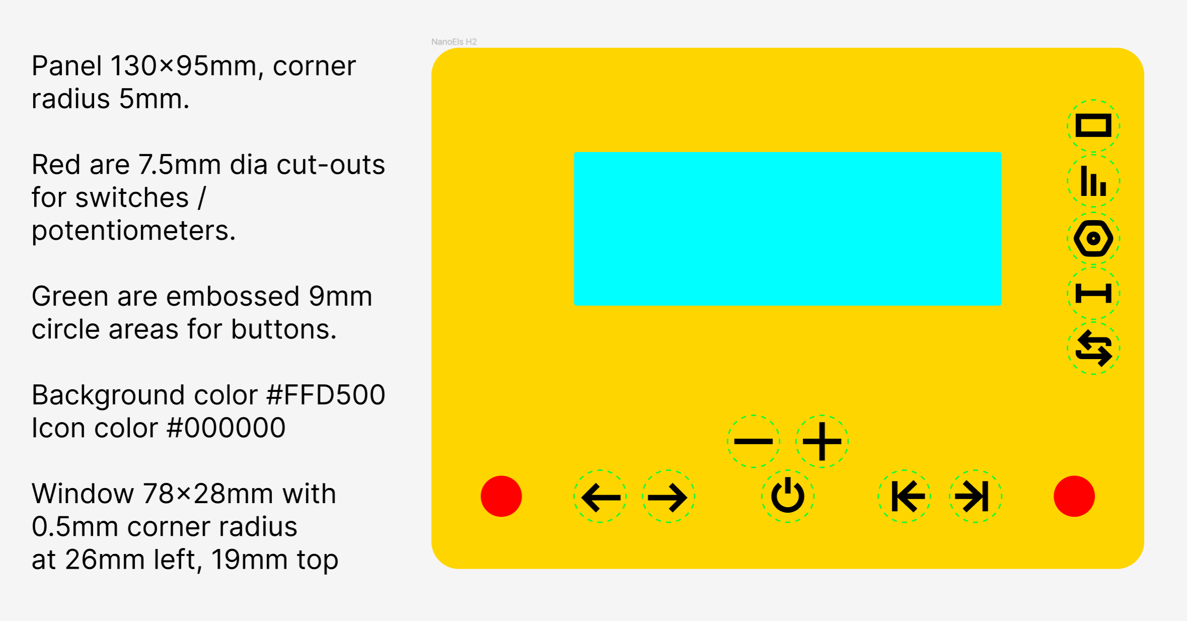
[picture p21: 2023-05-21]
h2/Hardware_20230521/H2-panel-guidance.png

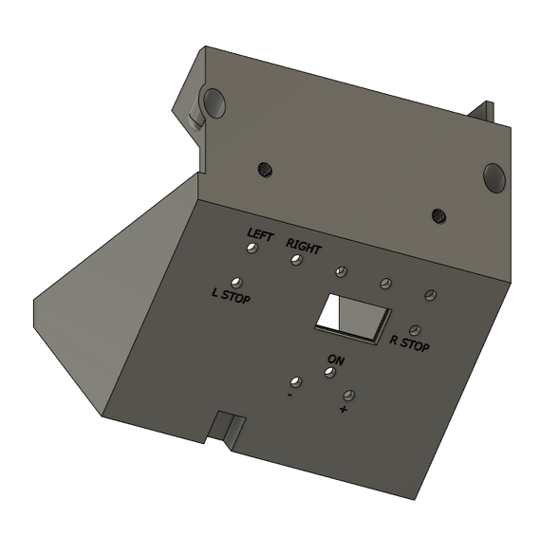
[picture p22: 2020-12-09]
h1/case/case-120mm-2m6-2m5-4m3.png

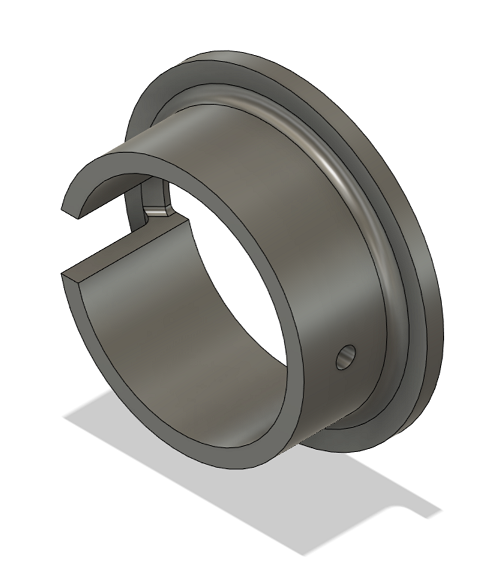
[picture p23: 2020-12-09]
h1/encoder/encoder-base-38.5mm-hole-m4-screw.png

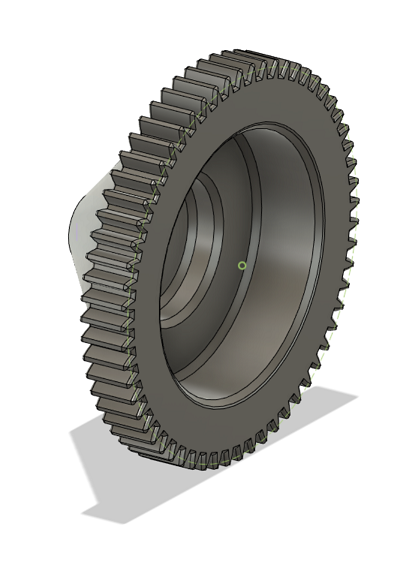
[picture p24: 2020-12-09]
h1/encoder/encoder-gear-60t-6.1mm-bore.png

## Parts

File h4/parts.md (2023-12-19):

# Building H4 from individual parts

## Printed circuit boards

H4 consists of 2 PCBs - main one with ESP32 and keypad with push switches.

[Gerber, BOM, pick and place files](https://github.com/kachurovskiy/nanoels/tree/main/h4/pcbs) can be found in the `pcbs` folder. EasyEDA source files are also provided.

Edits I would make for the next batch:

- Make `R7` a `10Ohm` resistor for optimal buzzer volume and current usage
- Remove `F2`, `R12`, `R16`, `R36` and `R37` (or replace with 0 Ohm resistors) as they limit current on outgoing `5V` pins to the point where some encoders and motor drivers can't operate

Additionally, the following parts need to be ordered as they're not included in the PCB BOM:

- https://www.lcsc.com/product-detail/_XFCN-_C2915256.html (2x)
- https://www.lcsc.com/product-detail/_XFCN-_C2889983.html (2x)
- https://www.lcsc.com/product-detail/_DIBO-_C395832.html (5x)

## Front panel

I ordered the front panels on https://www.jrpanel.com/panel/buy/ with the following settings:



Provide them with [h4-go-1.png](https://github.com/kachurovskiy/nanoels/blob/main/h4/graphics/h4-go-1.png) as a design guidance and [h4-go-2.pdf](https://github.com/kachurovskiy/nanoels/blob/main/h4/graphics/h4-go-2.pdf) for printing purposes.

If you'd like to make modifications to the panel design, open [h4.fig](https://github.com/kachurovskiy/nanoels/blob/main/h4/graphics/h4.fig) using [figma.com](https://www.figma.com) editor.

## Rear sticker

I ordered the rear stickers on [Sticker Mule](https://www.stickermule.com/de/products/rechteck-sticker) using [h4-labels.pdf](https://github.com/kachurovskiy/nanoels/blob/main/h4/graphics/h4-labels.pdf) in 75x30mm size. It's doubled up due to their minimum size requirements. 

## Case

Plastic case consists of front and back piece which can be found in the [case folder](https://github.com/kachurovskiy/nanoels/tree/main/h4/case) as `STL` files ready for printing. If you'd like to modify the models, FreeCAD source file is also provided.

Front piece is designed to accept nine M3 threaded inserts, each 4mm long (4 to connect the back piece, 5 to hold the keypad). You would also need 9 M3 screws, each 8mm long.

Back piece accepts two M5 threaded inserts, each 5mm long with 8mm outside diameter.

h4 inserts

An optional small plastic shim model is also provided that is intended to be placed between the display and the keypad PCB to make the top row of buttons supported from the back.

Prints can also be ordered online e.g. on https://3d.jlcpcb.com/3d-printing-quote.

## Display

5V [HD44780 2004 LCD display](https://www.azdelivery.de/en/products/copy-of-hd44780-2004-lcd-display-bundle-4x20-zeichen) or similar is required. 16-pin 2.54mm header is used to connect it to the main PCB.

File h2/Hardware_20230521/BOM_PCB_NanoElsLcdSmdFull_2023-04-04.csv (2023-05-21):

ID | Name | Designator | Footprint | Quantity | Manufacturer Part | Manufacturer | Supplier | Supplier Part | Price
1 | 1kΩ | BRIGHTNESS | RES-ADJ-SMD_3P-L4.5-W4.5-P2.30-LS6.2-BL-FS | 1 | 3314G-2-102E | BOURNS | LCSC | C780178 | 0.083
2 | 600Ω | L10,L11,L12,L13,L14,L15,L16,L17 | L0603 | 8 | GZ1608D601TF | Sunlord(顺络) | LCSC | C1002 | 0.001
3 | 100kΩ | R1 | R0603 | 1 | 0603WAF1003T5E | UNI-ROYAL(厚声) | LCSC | C25803
4 | 1kΩ | R2,R3,R4,R5,R6,R7,R8,R9,R10,R11,R12,R13,R14,R15,R16,R17 | R0603 | 16 | 0603WAF1001T5E | UNI-ROYAL(厚声) | LCSC | C21190
5 | JK-NSMD016 | FUSE,FUSE2 | F1206 | 2 | JK-NSMD016 | JK(金科) | LCSC | C369156 | 0.004
6 | 10uF | C1 | C0603 | 1 | CL10A106MA8NRNC | SAMSUNG(三星) | LCSC | C96446 | 0.004
7 | 100nF | C3,C21,C22 | C0603 | 3 | CC0603KRX7R9BB104 | YAGEO(国巨) | LCSC | C14663
8 | 1nF | C4,C5 | C1206 | 2 | 1206B102K202NT | FH(风华) | LCSC | C9196 | 0.001
9 | 1uF | C17,C19,C20 | C0603 | 3 | CL10A105KB8NNNC | SAMSUNG(三星) | LCSC | C15849 | 0.001
10 | PESD5V0S1BBN | D7,D8,D9,D10,D1,D2,D3,D4,D5,D6 | SOD-523_L1.2-W0.8-LS1.6-BI | 10 | PESD5V0S1BBN | BORN(伯恩半导体) | LCSC | C314264 | 0.004
11 | 1nF | C2,C6,C7,C8,C9,C10,C11,C12,C13,C14,C15 | C0402 | 11 | 0402B102K500NT | FH(风华) | LCSC | C1523
12 | TS-1006S-BR15026 | LEFT,MINUS,ONOFF,PLUS,RIGHT,STOPL,STOPR,K1,K2,K3,K4,K5 | SW-SMD_4P-L6.0-W6.0-P4.50-LS9.5 | 12 | TS-1006S-BR15026 | XUNPU(讯普) | LCSC | C2856659 | 0.009
13 | MFL2012SP401M1CTF | L1 | FILTER-SMD_4P-L2.0-W1.2-L | 1 | MFL2012SP401M1CTF | Sunlord(顺络) | LCSC | C2757906 | 0.015

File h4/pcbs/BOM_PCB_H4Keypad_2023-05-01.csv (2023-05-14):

ID | Name | Designator | Footprint | Quantity | Manufacturer Part | Manufacturer | Supplier | Supplier Part | Price
1 | GT-TC089C-H070-L1 | B0,B1,B2,B3,B4,B5,B6,B7,B8,B9,DOWN,F1,F2,F3,F4,F5,F6,F7,LDOWN,LEFT,LLEFT,LRIGHT,LUP,M1,M2,M3,M4,M5,M6,M7,M8,M9,MINUS,PLUS,RIGHT,START,STOP,UP,BS | SW-SMD_4P-L6.0-W6.0-P4.50-LS8.5 | 39 | GT-TC089C-H070-L1 | G-Switch(品赞) | LCSC | C843634 | 0.008

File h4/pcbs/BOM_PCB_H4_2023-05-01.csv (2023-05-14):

ID | Name | Designator | Footprint | Quantity | Manufacturer Part | Manufacturer | Supplier | Supplier Part | Price
1 | SRV05-4-P-T7 | TV1 | SOT-23-6_L2.9-W1.6-P0.95-LS2.8-BR | 1 | SRV05-4-P-T7 | PROTEK | LCSC | C85364 | 0.028
2 | KESD9B5VL | D21,D22,D23,D24,D25,D26,D27,D28,D29,D30,D31,D32,D33,D34,D35,D36,D37,D38,D39 | X1-DFN1006-2_L1.0-W0.6-P0.65-BI | 19 | KESD9B5VL | KUU | LCSC | C2892504 | 0.004
3 | 10kΩ | CONTRAST | RES-TH_RK09K113004U | 1 | RK09K113004U | ALPSALPINE(阿尔卑斯阿尔派) | LCSC | C202382 | 0.072
4 | 200Ω | R12,R16,R36,R37 | R0805 | 4 | 0805W8F2000T5E | UNI-ROYAL(厚声) | LCSC | C17540
5 | 1k | BRIGHTNESS | RES-ADJ-SMD_3P-L4.5-W4.5-P2.30-LS6.2-BL-FS | 1 | 3314G-2-102E | BOURNS | LCSC | C780178 | 0.083
6 | DB2EVC-3.5-4P-GN | AUX1,AUX2,ENCODER,X-MOTOR,Z-MOTOR | CONN-TH_4P-P3.50_DB2EVC-3.5-4P-GN | 5 | DB2EVC-3.5-4P-GN | DIBO(地博电气) | LCSC | C430552 | 0.025
7 | 10uF | C6,C3,C4,C13,C17 | C1206 | 5 | CL31A106KBHNNNE | SAMSUNG(三星) | LCSC | C13585 | 0.005
8 | 1N4148WS T4 | D20 | SOD-323_L1.8-W1.3-LS2.5-RD | 1 | 1N4148WS | CJ(江苏长电/长晶) | LCSC | C2128 | 0.002
9 | 120Ω | L1,L2,L3,L4,L22,L23,L24,L25,L26,L27,L28,L29,L31,L32,L33,L34,L36,L5,L6,L10,L11 | L0603 | 21 | CBM160808U121T | FH(风华) | LCSC | C62708 | 0.001
10 | SI2302ADS-T1 | Q1,Q2,Q5,Q6,Q7,Q8,Q9,Q10,Q11,Q12,Q13,Q14,Q15,Q16,Q18 | SOT-23-3_L2.9-W1.3-P1.90-LS2.4-BR | 15 | SI2302ADS-T1-VB | VBsemi(微碧) | LCSC | C725156 | 0.012
11 | 2kΩ | R1,R2,R6,R15,R17,R18,R19,R20,R22,R23,R24,R25,R26,R27,R28,R29,R30,R35,R38,R39,R40,R41,R42,R43,R44,R45,R48,R49 | R0603 | 28 | 0603WAF2001T5E | UNI-ROYAL(厚声) | LCSC | C22975
12 | 100Ω | R7 | R0805 | 1 | 0805W8F1000T5E | UNI-ROYAL(厚声) | LCSC | C17408
13 | 10kΩ | R13,R14 | R0603 | 2 | 0603WAF1002T5E | UNI-ROYAL(厚声) | LCSC | C25804
14 | 1nF | C19,C20 | C0402 | 2 | 0402B102K500NT | FH(风华) | LCSC | C1523
15 | 1uF | C1,C2,C7 | C0402 | 3 | CL05A105KA5NQNC | SAMSUNG(三星) | LCSC | C52923 | 0.001
16 | 5.1kΩ | R5,R31,R32,R33,R34,R3,R21 | R0603 | 7 | 0603WAF5101T5E | UNI-ROYAL(厚声) | LCSC | C23186
17 | 100nF | C5,C11,C12,C15,C18 | C0603 | 5 | CC0603KRX7R9BB104 | YAGEO(国巨) | LCSC | C14663
18 | 470Ω | R4,R11 | R0603 | 2 | 0603WAF4700T5E | UNI-ROYAL(厚声) | LCSC | C23179
19 | QMB-09B-03 | BUZZER | BUZ-TH_BD9.0-P4.00-D0.6-FD | 1 | QMB-09B-03 | 华能 | LCSC | C96256 | 0.021
20 | ESP32-S3-WROOM-1U-N16R2 | ESP | WIRELM-SMD_ESP32-S3-WROOM-1U | 1 | ESP32-S3-WROOM-1U-N16R2 | ESPRESSIF(乐鑫) | LCSC | C3013945 | 0.763
21 | TCA8418RTWR | KEYS | WQFN-24_L4.0-W4.0-P0.50-TL-EP2.5 | 1 | TCA8418RTWR | TI(德州仪器) | LCSC | C138713 | 0.12
22 | AMS1117-3.3 | LVR | SOT-223-3_L6.4-W3.5-P2.30-LS7.0-BR | 1 | AMS1117-3.3 | 国芯佳品 | LCSC | C2992570 | 0.006
23 | 918-468K2029E50000 | USB | USB-C-TH_918-468K2029E50000 | 1 | 918-468K2029E50000 | 精拓金 | LCSC | C709027 | 0.101
24 | CH9102F | USB2UART | QFN-24_L4.0-W4.0-P0.50-BL-EP2.5 | 1 | CH9102F | WCH(南京沁恒) | LCSC | C2858418 | 0.215
25 | SMD1812P030TF | F1 | F1812 | 1 | SMD1812P030TF | RUILON(瑞隆源) | LCSC | C20995 | 0.011
26 | nSMD010 | F2 | F1206 | 1 | nSMD010 | 台湾陆海 | LCSC | C70065 | 0.005
27 | S9013W | Q3,Q4 | SOT-323-3_L2.0-W1.3-P1.30-LS2.1-BR | 2 | S9013W | CJ(江苏长电/长晶) | LCSC | C37634 | 0.005

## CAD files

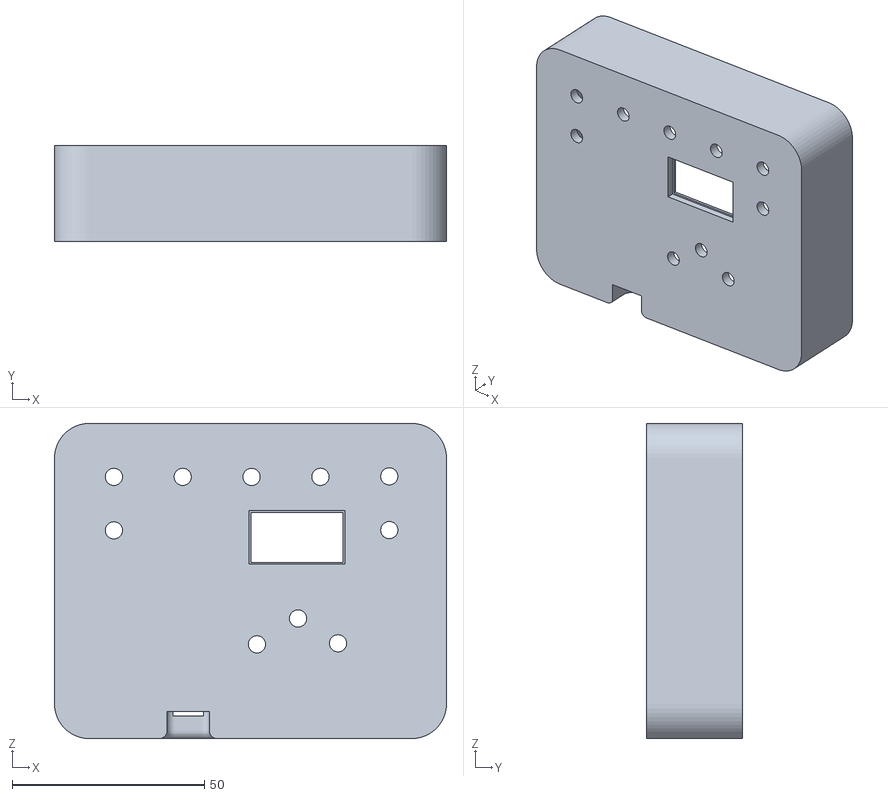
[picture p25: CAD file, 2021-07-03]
h1/case/nanoels-box-part1.stl
102.0 x 25.0 x 82.0

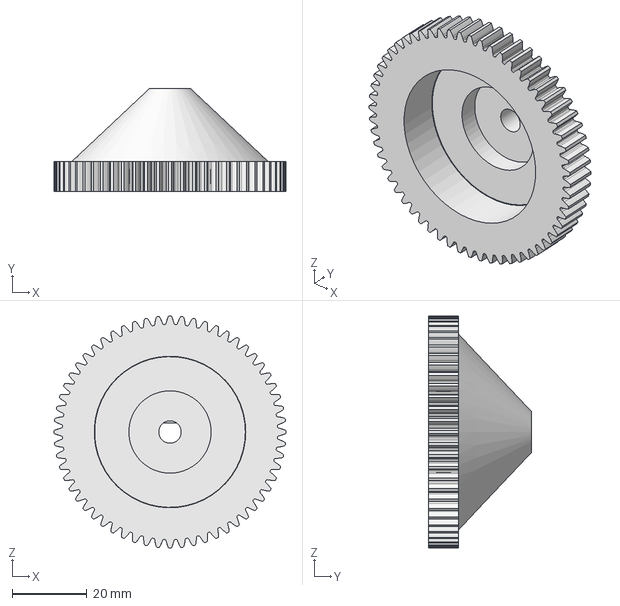
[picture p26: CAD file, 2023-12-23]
h1/encoder/EncoderMount38.4mm-Wheel.step
62.0 x 27.5 x 62.0 mm

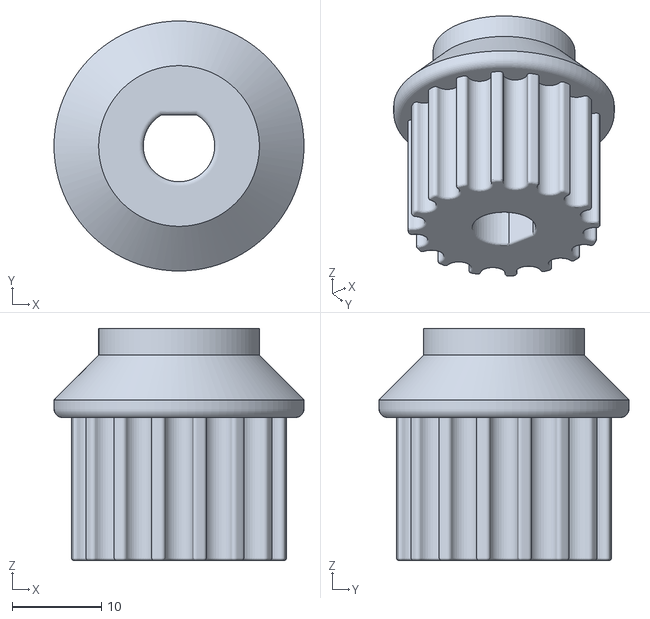
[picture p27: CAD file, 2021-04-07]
h1/stepper/htd5m-16t-8b.stl
28.0 x 28.0 x 26.0

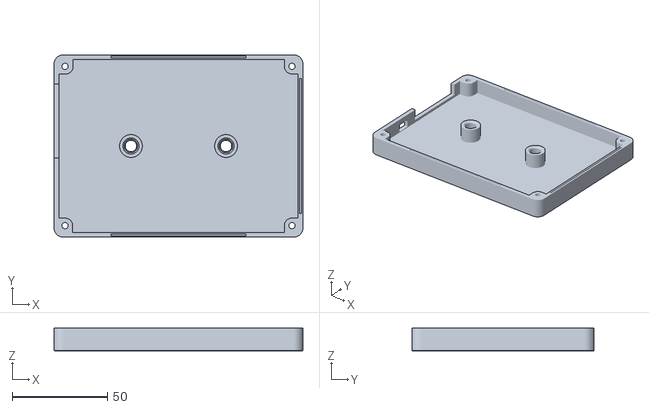
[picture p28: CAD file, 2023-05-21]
h2/Hardware_20230521/NanoElsH2-Back.stl
131.0 x 96.0 x 12.0

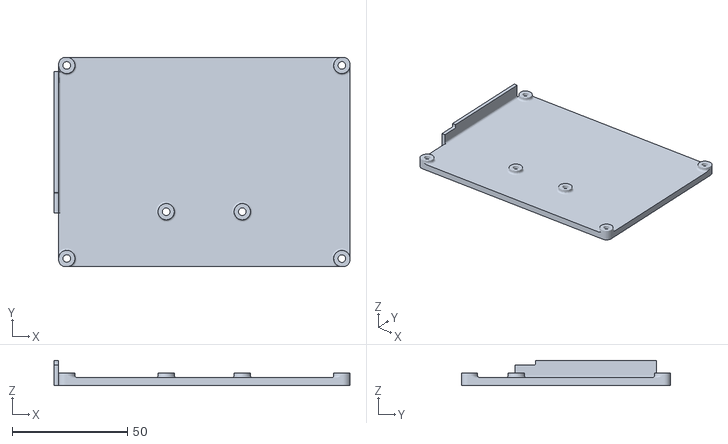
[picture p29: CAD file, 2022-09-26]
h2/nanoels-lcd-lid.stl
128.5 x 90.9 x 10.9

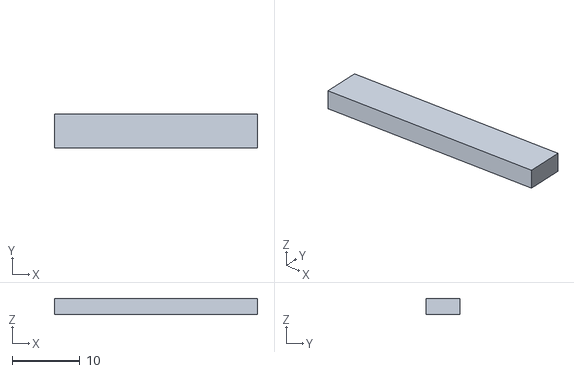
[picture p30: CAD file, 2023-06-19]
h4/case/KeypadShim5x30x2.4-Body.stl
30.0 x 5.00 x 2.40

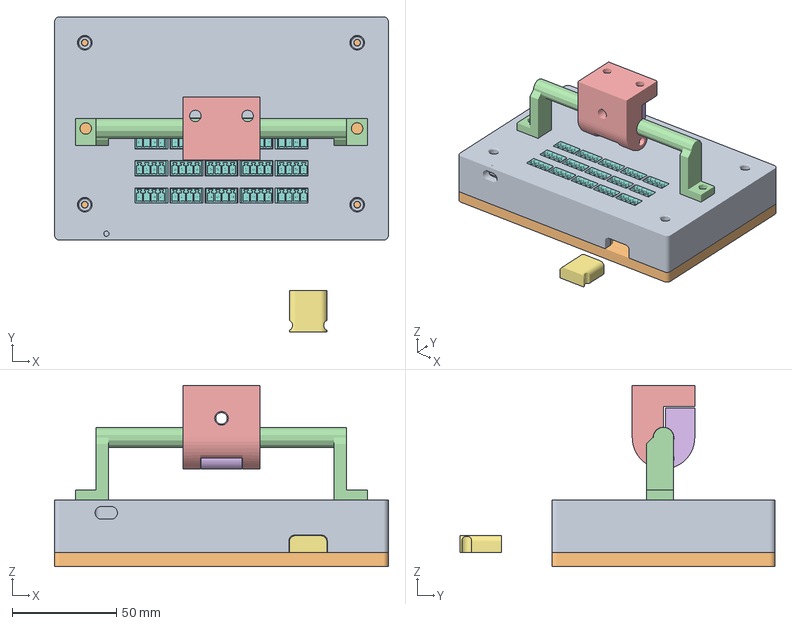
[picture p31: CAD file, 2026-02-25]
h5/case/h5.FCStd
160.0 x 151.1 x 86.8 mm
h5case
NX8048P050-011C
esp32-wroom-1
h5handle
h5mount1
h5mount2
sdhandle
pcb

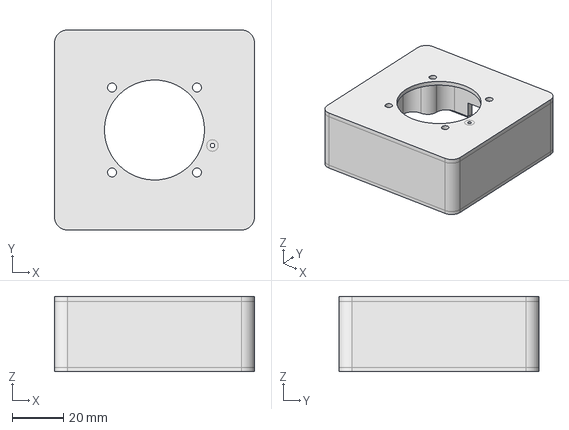
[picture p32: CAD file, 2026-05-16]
h5/joystick/Joystick-CaseTop.step
78.0 x 78.0 x 29.4 mm

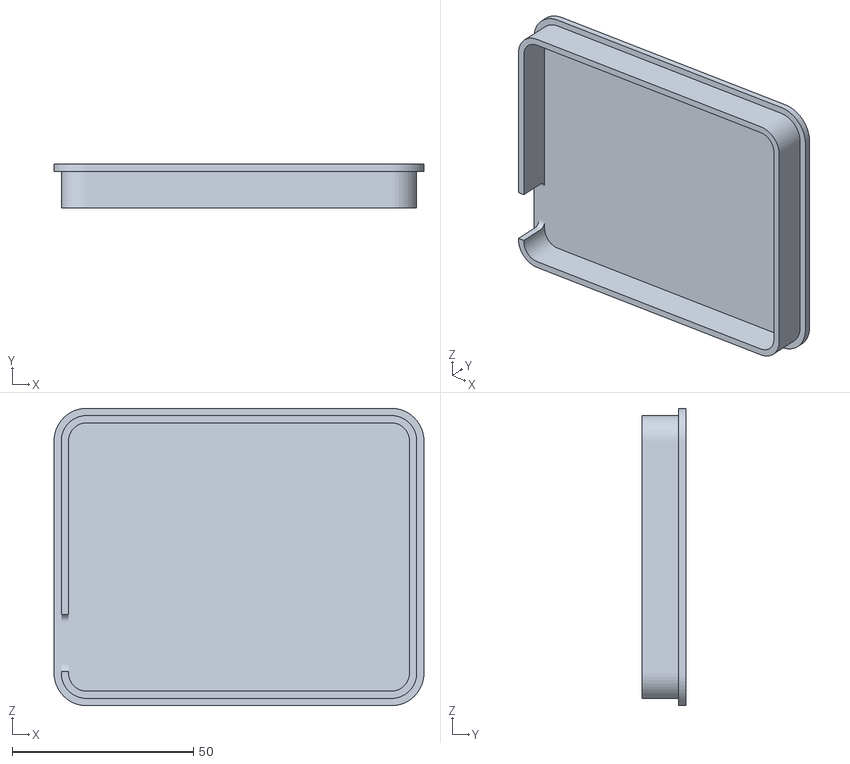
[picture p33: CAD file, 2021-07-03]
h1/case/nanoels-box-part2.stl
102.0 x 12.0 x 82.0

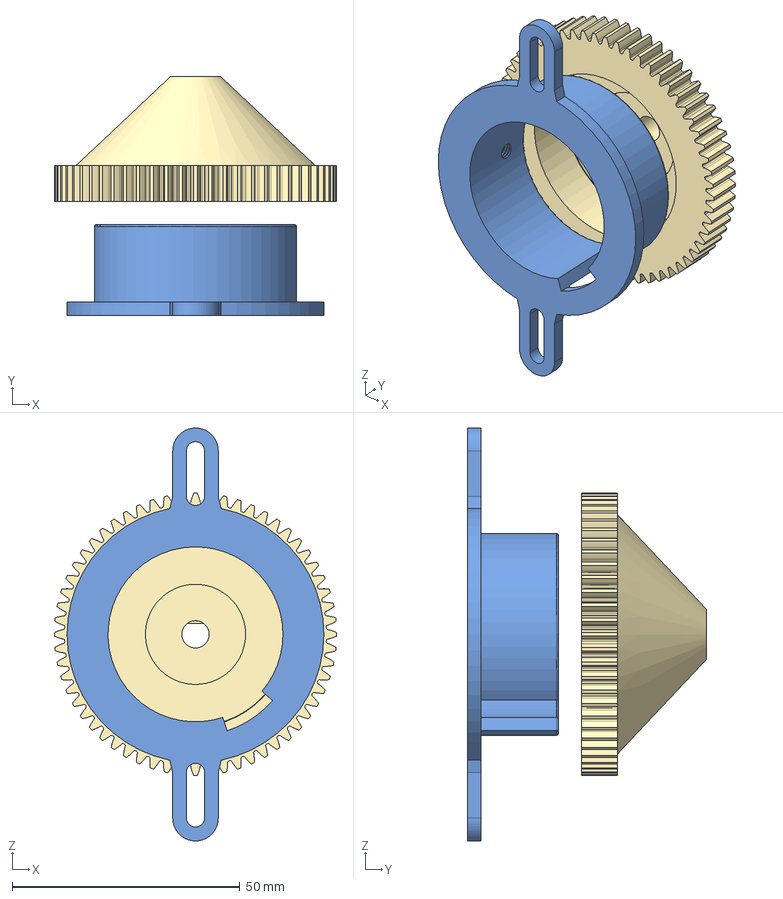
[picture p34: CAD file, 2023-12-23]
h1/encoder/EncoderMount38.4mm.FCStd
62.0 x 52.5 x 90.7 mm
Wheel

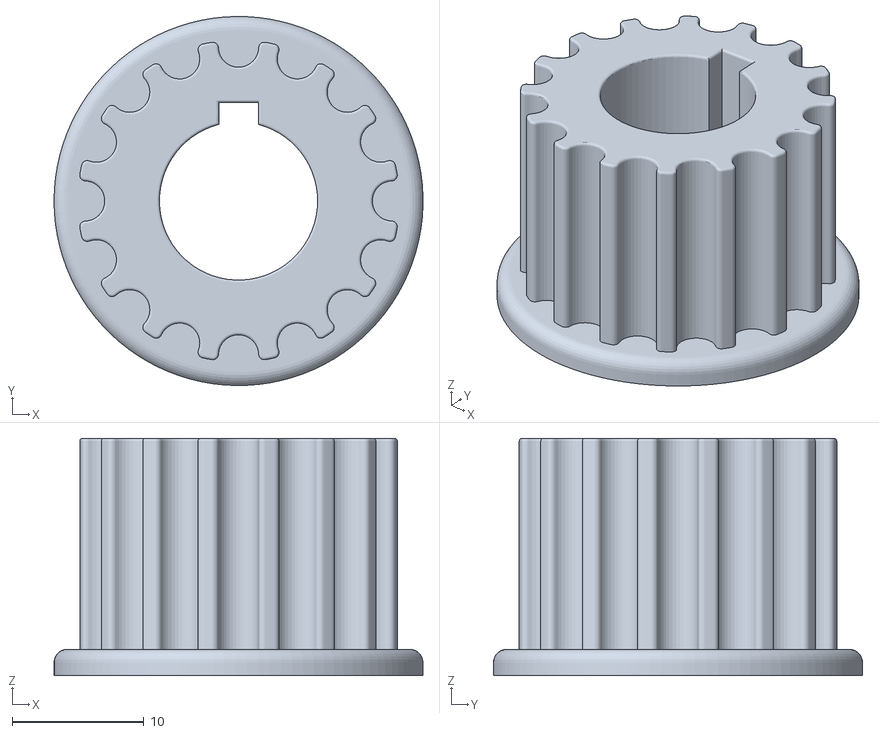
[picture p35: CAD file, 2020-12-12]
h1/stepper/htd5m-16t-12b.stl
28.0 x 28.0 x 18.0

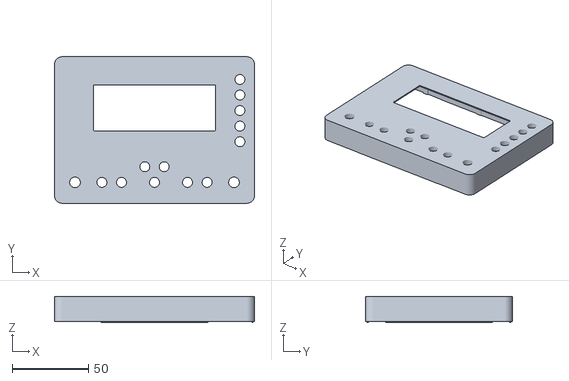
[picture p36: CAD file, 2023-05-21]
h2/Hardware_20230521/NanoElsH2-Case.stl
131.0 x 96.0 x 17.0

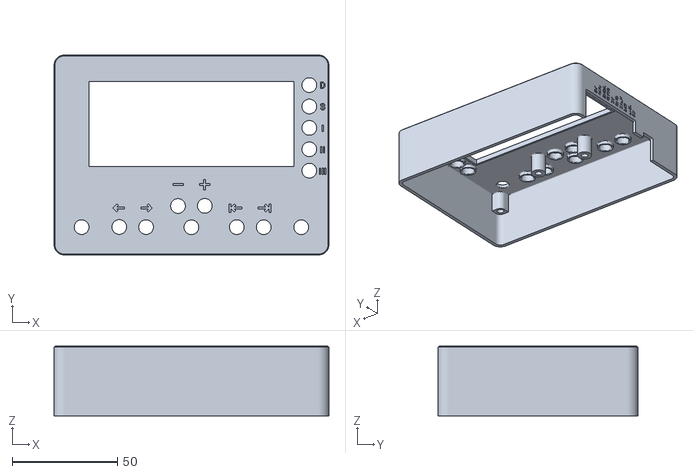
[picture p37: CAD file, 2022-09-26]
h2/nanoels-lcd-case.stl
130.5 x 94.9 x 33.0

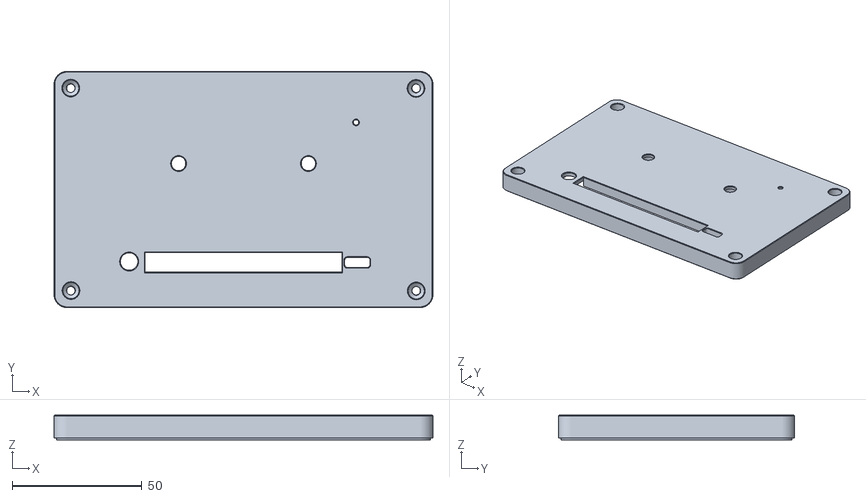
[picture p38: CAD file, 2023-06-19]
h4/case/NanoElsH4-3dp-Back.stl
146.0 x 91.0 x 9.50

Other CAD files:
h5/case/h5sdhandle.step
h5/joystick/Joystick-Detent.step
h1/case/case-120mm-2m6-2m5-4m3.stl
h1/encoder/EncoderMount38.4mm-Body.step
h1/case/nanoels-box.f3d
h1/encoder/encoder-base-38.5mm-hole-m4-screw.f3d
h1/encoder/encoder-base-38.5mm-hole-m4-screw.stl
h1/encoder/encoder-gear-60t-6.1mm-bore-for-encoder-59mm-tall.stl
h1/encoder/encoder-gear-60t-6.1mm-bore.stl
h1/stepper/htd5m-16t-10b.stl
h1/stepper/htd5m.f3d
h1/stepper/stepper-gear-nema23-50t-10mm-10mm.stl
h1/stepper/stepper-mount-nema23-28mm-hole.f3d
h1/stepper/stepper-mount-nema23-28mm-hole.stl
h1/stepper/stepper-to-gear-adapter-12mm-10mm.stl
h2/Hardware_20230521/NanoElsH2.FCStd
h2/nanoels-lcd-button.stl
h4/case/NanoElsH4-3dp-Front.stl
h5/case/esp32devkit.FCStd
h5/case/h5handle.step
h5/case/h5mount1.step
h5/case/h5mount2.step
h5/case/pcb.obj
h5/joystick/Joystick-CaseBottom.step
h5/joystick/Joystick.FCStd

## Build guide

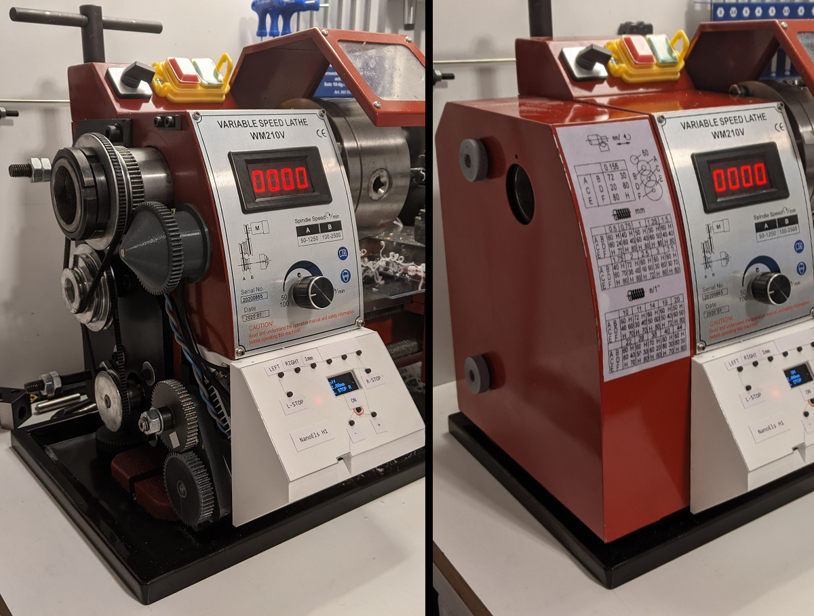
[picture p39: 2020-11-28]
h1/buildexamples/buildexample1.jpg

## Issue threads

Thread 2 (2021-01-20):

Hello, Someone could explain how the program works? Thanks

lewiss66, 2021-01-20:

kachurovskiy, 2021-01-20:
It works by first calling setup() function and then calling loop() infinitely.

setup() among other things adds an interrupt handler spinEnc() which is called every time a rotary encoder makes a step, adding those steps up in `spindlePos` variable.

loop() calculates the stepper position based on `spindlePos` and compares it to current stepper position. Stepper is moved if needed.

lewiss66, 2021-01-21:
Thanks, It a good help to start understanding !

Closed 2021-01-30.

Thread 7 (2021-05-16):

Adaption for Mach4

Charly333, 2021-05-16:
Hi Maxim,

what a hell of great ideas!

I´ve just ordered my lathe and will adapt it to Mach4 as I did with my mill.

Those motor holders of your´s are well designed, but i´m quite familiar with that heated up nema steppers on plastic holders problem ;) Milled some aluminum holders for my 3d printer to get rid of all this ongoing deformations not only from temperature but from pressure and load change. So for the lathe too, there will be aluminium ones. Therefore I´ll need to make some adaptions on your sketches to make it millable and maybe suitable for closed circuit steppers with different form factors. Could you hand over those sketches as f3d files too? Only found STL.

One off the main problems left will be to adapt the rotary encoder to my PoKeys57CNC board. Any advice in this? You´ve realized a degree readout for the chuck - what is the smallest subdevision you can get out of this?

Second open question is to have chuck rpm programmable. Any idea if motor is adaptable to a normal VFD Inverter that´s triggered buy 0 to 10V?

Maybe a closed loop servo to drive the chuck might be the better solution for those two open questions - how you feel about it?

Reg. Charly

kachurovskiy, 2021-05-16:
Hi Charly, thank you.

> heated up nema steppers on plastic holders problem

Yes, plastic has it's limitations. Have you considered PETG? It has a wider temperature range than PLA and is said to creep less with time.

> Could you hand over those sketches as f3d files too? Only found STL.

Sure, which models exactly are you interested in?

> One off the main problems left will be to adapt the rotary encoder to my PoKeys57CNC board. Any advice in this?

Not sure what you mean here. I assume you'd need to mechanically connect the rotary encoder to the spindle and electronically connect it to the board. I've never worked with that board though.

> Second open question is to have chuck rpm programmable. Any idea if motor is adaptable to a normal VFD Inverter that´s triggered buy 0 to 10V?

Sorry, I've never worked with that, NanoEls doesn't control the spindle motor - only the lead screw.

> Maybe a closed loop servo to drive the chuck might be the better solution for those two open questions - how you feel about it?

Closed loop servo motors/drivers are expensive and the motor might not fit in the enclosure of the default DC motor that most of Chinese lathes come with. Other than looking them up on AliExpress I have no experience with them though :)

Best wishes!

Charly333, 2021-05-16:
Hi, thank´s for your quick response.

Did try a lot, different plastics. PETG is bit better, but I´ve 2,8 nm on y axis of printer (4 colors with 4 separate servo lifted hotends and 4 separate extruders what makes the print catridge somewhat heavy...) and that´s to much for PETG too.

I´m interrested in drawings of
- that side mount for the nema that´s sitting just below your box driving the lead screw
- cs2-1.stl

Could solve that encoder problem with PoKeys - if interessted here´s the description:
https://blog.poscope.com/wp-content/uploads/2017/01/DM-W16-p-57-63.pdf

kachurovskiy, 2021-05-16:
Here's the stepper mount - [nema23anglemount v9.zip](https://github.com/kachurovskiy/nanoels/files/6489970/nema23anglemount.v9.zip) - but I don't think there are any `cs2-1.stl` files in this repo - could post an URL to the image/stl file?

Charly333, 2021-05-17:
Great.  Thank you.

The cs2-1.stl was in a zip I´ve downloaded from here. Looks like this:
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

kachurovskiy, 2021-05-17:
Sure, here is the latest version of that model - [Cross Slide 2 v15.zip](https://github.com/kachurovskiy/nanoels/files/6496828/Cross.Slide.2.v15.zip)

Charly333, 2021-05-18:
Thank´s a lot. Should be easy to adapt for milling. Motor Housing needs a bit more opening and will be milled from two sides to get sharp corners wherevere needed. And front-plate - geared side - should be a bit thicker. Might have to reduce the gear thickness a bit. May hand back the adapted version after milling and testing if you like.

Is your solution of rotation readout precise enough for indexing gears? At the moment I´m producing gears by printing them with stiff transparent filament in vasemode. Filling up with glas fiber enhanced resin, it´s got more strengh than filament, but the working edges from that filament layer arn´t that brickle as if made of resin only. But even if having a 5mm clamp from a big one old style Lüsterklemme resined in for fixing gear on axis, it´s worked out after a while, specially if it´s used for bidirectional purposes...

kachurovskiy, 2021-05-18:
> Should be easy to adapt for milling.

It was designed for 3D printing, would be pretty hard to mill this if possible but let me know if it works.

> Is your solution of rotation readout precise enough for indexing gears?

Not sure what you mean. There's always backlash between gears so calculating the cutter position by stepper turns is only valid as long as direction is unchanged and stepper didn't lose steps.

There's also an option to order metal gears from China, they're inexpensive.

Another option suggested in a YouTube comment was to use chevron (herringbone) gears instead of standard ones. There are plugins for generating them both in Fusion and in FreeCAD. I didn't try them though and gear thickness might be a problem.

If you want to have no backlash, you'd need to switch from lead screws to ball screws and belt drive or direct drive.

Closed 2021-06-11.

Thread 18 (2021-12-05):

Modified mount for slightly different encoder

mockendon, 2021-12-05:
The encoder I bought is a little different from the one you show.  The somewhat bulky cable exit gland prompted a modification.  I also added some tabs for machine screws in tapped holes in the headstock casting - one is oval to allow adjustment of backlash between the gears.

[https://www.thingiverse.com/thing:5156081](url)

mockendon, 2021-12-05:
Also I modified the stepper mount to add a pinch bolt.

[https://www.thingiverse.com/thing:5156087](url)

kachurovskiy, 2021-12-05:
Matt, awesome, thank you! Linked your models in https://github.com/kachurovskiy/nanoels/commit/70b1cbc75f77e74161bcae6a57df76f97c80c6c7

Closed 2021-12-05.

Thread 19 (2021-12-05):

An 80T encoder gear for 40T spindle gear

mockendon, 2021-12-05:
Another remix - my spindle has a tiny 40T gear so this is needed to fit in under the pulleys.  Reduced pulses per revolution but cheaper and quicker than trying to source a new spindle gear.  Just #define ENCODER_STEPS to half of the value for the encoder used (2:1 reduction).    The axle bore is a pilot size as I found it best to drill to size on the lathe to improve concentricity.

[https://www.thingiverse.com/thing:5156106](url)

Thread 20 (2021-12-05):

Stepper mount with a pinch bolt

mockendon, 2021-12-05:
Just a tiny tweak - added an M2 pinch bolt to hold the collar a little more securely

[https://www.thingiverse.com/thing:5156265](url)

PS Really enjoying this build, thank you.  Was interested in Clough42's solution but that was waaaaay more that I needed for my little lathe.   I'm excited to have a power feed with sensible feed rate as well as threading without messing in the gear box.

Closed 2021-12-05.

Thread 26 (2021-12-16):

Word of caution for older mini-lathes

mockendon, 2021-12-16:
In your readme you allude to lathe main board (speed controller) failure associated with a short to the case from the control panel.  I was, therefore, very careful never to run the lathe when the panel was 'floating'.  However - once the project was finished and everything was working perfectly (amazing, by the way - another post with pics of the finished article will follow) I gave in to the obvious temptation to 'see what it could do'  ie. took the lathe speed up to the max.  That is what blew up my (rather old) control board.  The mode of failure was interesting (a pair of diodes across the supply failed short circuit) but it had nothing to do with NanoELS it is just that I had almost never run the lathe at top speed and the ageing control electronics wasn't up to it.  Still, it was an interesting fault finding mission and I learned something about SCRs as high voltage DC speed controllers along the way.

kachurovskiy, 2021-12-16:
Matt, great data point, thanks for sharing, hopefully your warning will save a few control boards.

Closed 2021-12-16.

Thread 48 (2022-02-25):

PCB: text is partially obscured by screw terminals

bestbean, 2022-02-25:
When screw terminals are used, they partially obscure inscriptions
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
.

kachurovskiy, 2022-02-25:
That's because the screw terminals are meant to be soldered from the bottom: https://github.com/kachurovskiy/nanoels/blob/main/h1/pcb/nanoels-pcb-h1.png :)

bestbean, 2022-02-25:
True.
I could have seen that.
Please close this issue.

kachurovskiy, 2022-02-26:
Nice job on the PCB assembly. Hope it works 👍

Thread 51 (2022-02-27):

readme: typo

bestbean, 2022-02-27:
(https://github.com/kachurovskiy/nanoels#5a-power-supply)5A power supply
Arduino Nano doesn't draw much current so a 0.5A phone charger would work

May be:
5V power supply
Arduino Nano doesn't draw much current so a 0.5A phone charger is more than sufficient

kachurovskiy, 2022-02-27:
Thank you! :)

Closed 2022-02-27.

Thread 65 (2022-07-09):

AIN device connected to A6 and A7 pins

oppozith, 2022-07-09:
Hi!
What is the device that marked as "AIN" on scheme connected to A6 and A7 pins?

Thanks.

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

kachurovskiy, 2022-07-09:
@oppozith A6 and A7 aren't used by NanoEls but are exposed in case you want to modify the code and use them for something. Sorry for confusion. Thanks!

oppozith, 2022-07-09:
Understood.
Thank you for your projects!

Closed 2022-08-10.

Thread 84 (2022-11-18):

可以用esp32来制作吗？

jpdd521, 2022-11-18:
可以用esp32来制作吗？

kachurovskiy, 2022-11-18:
Hi @jpdd521, yes, you could re-work this code to work on ESP32 but it's non-trivial - pins need to be re-assigned, 3V vs 5V needs to be checked, you'd need a different PCB, etc. It's a big change.

Closed 2022-11-28.

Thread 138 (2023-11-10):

Nano ELS

jvojvodi, 2023-11-10:
Hi
I put all the components together and it seems to work. But as a beginner I have a problem with setting up hardware and software. Which lines of code should be aligned and to which values and how to set the DIP switches on the stepper driver. The stepper is directly connected to the leading spindle with a pitch of 2.5 mm. Equipment specification attached.

Thanking you in advance.

[Equipment for ELS.pdf](https://github.com/kachurovskiy/nanoels/files/13319161/Equipment.for.ELS.pdf)

kachurovskiy, 2023-11-11:
Hi @jvojvodi,

1. Spindle direction: show angle on screen using top-right button. Rotate the chuck forward manually - angle should increase. If it decreases, swap encoder signal wires in the terminal.
2. Motor direction: try LEFT and RIGHT buttons - if motor is moving in the wrong direction, change SW5 DIP switch position
3. Looks like your version of driver CL57T V3.0 doesn't allow setting 200 steps resolution via DIP switches according to https://www.omc-stepperonline.com/download/CL57T.pdf so you'd either have to buy a V4.0 version of this driver or figure out if it's possible to use software to configure 200 steps - https://www.omc-stepperonline.com/closed-loop-stepper-driver-0-8-0a-24-48vdc-for-nema-17-23-24-stepper-motor-cl57t - NanoELS H2 can work with 800 steps but you will be limited in terms of motor speed you can achieve.
4. Is your encoder directly connected to spindle 1:1? In this case line 6 in h2.ino already uses `#define ENCODER_STEPS 600.0` and doesn't need to be changed.
5. Line 7 says `#define MOTOR_STEPS 200.0` - if you end up using 800 steps, change that to `#define MOTOR_STEPS 800.0`
6. Line 8 says `#define LEAD_SCREW_DU 20000.0` - your leadscrew pitch is 2.5mm so change it to `#define LEAD_SCREW_DU 25000.0`

jvojvodi, 2023-11-13:
Yes, now I understand where my problem is.

The encoder is in a ratio of 2:1 (48 teeth shaft : 24 teeth encoder). does that mean line 6 in h2 should be 300?

I will try with DIP 800, if it doesn't work, substitute for V4.0

In any case, I am very grateful for the reply

Greeting

kachurovskiy, 2023-11-13:
> The encoder is in a ratio of 2:1 (48 teeth shaft : 24 teeth encoder). does that mean line 6 in h2 should be 300?

For one turn of the shaft you'd have 2x impulses generated so use `#define ENCODER_STEPS 1200.0`. You can then enable displaying of angle on screen and check than turning the spindle by hand 1 turn results in angle changing by 360 degrees to it's start value.

Good luck!

jvojvodi, 2023-11-13:
Tx

Closed 2023-11-13.

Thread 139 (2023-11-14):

NanoELS - try first

jvojvodi, 2023-11-14:
I need help
Everything is connected. (see pictures) The encoder makes a full circle on the display and shows an angle of 360°. Correct.
The problem is that the stepper does not start.
No matter what I do, the stepper stops.
Where am I wrong.

[Greeting

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

jvojvodi, 2023-11-14:
The video is not ideal, the display is not visible in wide view. But maybe this one will help.
The third and fourth lines of the display disappear when the encoder is turned. Is that normal?
Also, the stepper heats up a lot in this experiment.

https://github.com/kachurovskiy/nanoels/assets/150443240/8ba8e45f-0c49-4ddd-8657-60c17f61a30d

kachurovskiy, 2023-11-14:
Bottom lines disappearing during motion is intended since Nano only has 1 core and can either drive the motor or update the screen.

Look for the 24/5v switch on the side of your driver, ensure it's in the 5v position.

jvojvodi, 2023-11-15:
5V works wonders:) Everything works fine on the test bench. Now comes the implementation on my DIY lathe.
Thanks again
Greeting

Closed 2023-11-15.

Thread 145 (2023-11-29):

Slotting mode idea

digiexchris, 2023-11-29:
How hard would it be to add a slotting mode? For example, for broaching an internal keyway using tiny infeeds of the cross slide, and moving the carriage left and right.

Example:
https://youtu.be/vk6msRj_tcQ?si=Dp1TDIgzHQsS9AoH&t=264

The way I do it on my 10x32" lathe is by barely touching, then move the carriage left to scrape one cut, then go to the start, feed in another .0005" (inch lathe) or .001" depending on how wide the slot is, and move it again. It would be nice to automate this with the H4, so I can say cut the slot to my X limit, and define the depth of each pass., and with a configurable left and right speed. The right speed can be much faster than the left speed due to the smaller torque requirement.

The difference with the turning mode is that the spindle obviously must not be turning, otherwise the automatic turning mode would do the job.

There is one complication for a blind slot (a slot that does not extend through the part entirely), the chips will pile up in the hole and prevent the tool from cutting the full depth. So I manually stop short as I'm progressing. For example, if my depth of cut is 0.0005, then the next pass must stop 0.0005" short of the left stop. If it's a through hole, that's not required though.

Just an idea. I was going to do a PR and implement it myself, but finding the time to dedicate to that is difficult for me at the moment. And I'm able to slot manually using the left and right moves anyway.

digiexchris, 2023-11-30:
SPEED_MANUAL_MOVE works for my case, because I use a large closed loop servo so the torque doesn't decrease as rpm increases, but the closed loop stepper I replaced did suffer from torque drop as rpm increases (as do all steppers). So for my use case, SPEED_MANUAL_MOVE would be fine. Later on though if people have trouble with it, we may want to consider a configurable slotting cut speed and then slotting retract speed can equal SPEED_MANUAL_MOVE.
#define SPEED_SLOTTING_CUT = SPEED_MANUAL_MOVE /2
#define SPEED_SLOTTING_RETRACT = SPEED_MANUAL_MOVE

or something. No big deal though, starting with SPEED_MANUAL_MOVE for everything and seeing how that works might be good enough.

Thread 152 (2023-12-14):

Encoder atomic operation improvement, Request for comments

digiexchris, 2023-12-14:
Hi Maxim, any interest in me making a PR for this? I did a small scale test and it seems to be an improvement, but I'm planning on doing a full multi-hour smoke test before submitting a PR, but wanted to ask if you would like me to do this, or do it yourself, or not bother with either?

https://github.com/kachurovskiy/nanoels/commit/2d94347bcc014ef85027dca51b381731493b259e

Turning off interrupts to process critical flows without memory corruption from an interrupt is common practice in the arduino space, particularly where interrupts are used in low speed (human scale speed) and non-critical operations like UI encoders. It's a common way to do it in the arduino space particularly since AVR doesn't support atomic operations larger than 1 byte. The issue I'm solving is there is a non-zero chance that a pulse interrupt is missed in that time. It's actually quite measurable on my machine with a much coarser leadscrew than the reference lathe, and gets worse with higher RPMs.

Considering the esp32/xtensia architecture does support C++11 atomic operations properly, I made a small quick change to use them for the critical variables, and removed the sections turning off and then on again the interrupts.

I've done some light testing on my bench rig but I plan on doing a complete test plan showing the before and after results, using an additional esp32 to emulate an encoder. At the end of a several day long run, the nanoels pulse count and the simulator pulse count should match within 1 interrupt edge.

kachurovskiy, 2023-12-14:
Hey Chris, huge thanks for sharing this.

1. According to my tests long reads/writes are atomic in ESP32 - https://t.me/MaximKachurovskiy/119 - if you can prove otherwise it would be a big contribution to the world. See also https://esp32.com/viewtopic.php?t=4686 - longs are 32 bit.
2. Blocking interrupt doesn't cause them to be missed - merely delayed until the block is lifted. Only case when an interrupt is missed is if 2 or more interrupts arrived during the block.

In https://github.com/kachurovskiy/nanoels/commit/2d94347bcc014ef85027dca51b381731493b259e the code between `noInterrupts()` and `interrupts()` is just 2 lines with long arithmetic - I suspect they take `5ns` or less. Let's say we run 10000rpm spindle and 3600 pulses encoder - that works out to 597600 pulses per second or `1673ns` interval between pulses. Looks like there's a good safety margin?

At the same time, I do also have problems with encoder drifting away over time at high RPM. I believe the issue could be a hardware limitation of H4 at this point though - to be solved by the 3rd encoder signal line Z which would report a full turn.

There's also something I don't quite understand wrt. rotary encoders related to differential signal handling and using 2 signal lines for both A and B and maybe using optical isolation but I didn't investigate that.

Cheers!

digiexchris, 2023-12-15:
The more I think about it, the more I think it's not actually a non-atomic operation problem, though I do feel that turning off interrupts is a bit of a sign of an architectural issue. I did attempt to go after the easy to implement solution first :D I suggest that the esp32 pulse count peripheral might be a better choice for counting, and reorganizing things to not require mutexes/semaphores as much as possible so that inter-core operations are not blocked on the same chunk of code. though that doesn't get around the below capacitance issue.

 I've done some playing with optical sensors and interrupts in a different application in the mean time since posting that, and I have a feeling that we may be seeing more effects from a long rise time due to capacitance causing what looks like missed interrupts when it's actually multiple pulses getting combined by floating slightly above or below the signal HIGH threshold due to a slow rise time in the LC filter on the input to the GPIO.

 Additionally, quick math suggests the LC filter is going to make a resonant frequency at around 10hz, and it will act to smooth out the pulses above and below that. The rise time is estimated at around 0.0105 seconds (depending on Q factor and a pile of things I didn't measure).

 The threshold between a LOW and a HIGH is just 0.5v, low being 0.25, high being 0.75, and according to quick calculations, the resonant frequency of the filter is around 10hz so it'll progressively work to smooth out ripples faster and slower than that. The math could very easily be wrong, I'm going to investigate this with my 500mHz oscilloscope later. It will be easy to see on that, I'll stick one probe on the input to the filter, and the other on the output.

 I can't find it now, but I came across a few people suggesting that rise time and slope are more critical when using interrupts than when using a polling system. It seems to align with my experience, being that more square edged pulses are detected more reliably by most microcontrollers.

 Since my encoder supports 24v levels as well, I'm toying with the idea of using a simple level shifter, and replacing the inductor with a 0ohm resistor. Then, the signal to noise ratio would be very good (a few 10's of millivolts vs 24v), and the rise time becomes the simple DC time constant of the capacitors, rather than being a resonant circuit due to the inductor.

as per 2, since the esp32 is running FreeRTOS, turning interrupts off using the arduino-esp32 abstraction only turns off interrupts on the arduino core, and leaves them enabled on the other core, which is dangerous https://docs.espressif.com/projects/esp-idf/en/v4.2-beta1/esp32/api-guides/freertos-smp.html#critical-sections
https://github.com/espressif/esp-idf/issues/7367
turning off interrupts isn't a good way to guarantee consistency between tasks. portENTER/EXIT_CRITICAL is the proper FreeRTOS way of handling shared data multi-core.

There is conflicting info if the esp32 queues pending interrupts with port_DISABLE_INTERRUPTS or stops them from being triggered at all, though the freertos documentation suggests that disabling the interrupt makes it ignore the state of the pin. The pending interrupt buffer isn't infinitely big either.

This brings up another point though, the arduino wrapper costs quite a bit of time. I have measured as high as 3 microseconds with the bare esp-idf interrupt api, and with the arduino wrapper on top, it goes up to 30 to 40 us. Which means at best, with no arduino wrapper, we can do 1 million interrupts per minute, and 10,000 rpm at 600 counts (1200 pulses, with the two interrupts) requires 1.2 million. That's also if we're doing nothing else with the system and there is never any contention. That goes down to 100,000 with the arduino wrapper, falling an order of magnitude short. So I think with the reference hardware, we have a theoretical maximum rpm of 1,666 rpm (which possibly coincidentally, is the speed that I start seeing the problems very frequently)

I'm also investigating dedicated SPI attached quadrature counter ICs, they're way faster for the specific task and a simple loop can just poll it for counts. I'm imagining an architecture where a single timer loop can poll for a count, compare to last count, and do the step planning, all in the same scope. It's going beyond the scope of this issue of course, but I'm thinking that since the esp32 is capable of assigning any pin as SPI pins, we could use some of the unused terminals to a simple single board decoder module.

Sorry for jumping topics so many times, just things I've been thinking about!

kachurovskiy, 2023-12-15:
Chris,

1. Is the problem you're seeing causing extra pulses or missed pulses? Please double check as this is critical for further reasoning.
2. It's easy to test whether `noInterrupts()` is the root cause - just remove noInterrupts/interrupts calls from https://github.com/kachurovskiy/nanoels/blob/main/h4/h4.ino#L2988-L2991 and see if this changes anything
3. To make the case for that 4-line code block taking more than a handful of nanoseconds it'd be nice to run a simple speed measurement on it - getting micros, running the code block 1000 times, getting micros again and calculating the run time
4. "we can do 1 million interrupts per minute, and 10,000 rpm at 600 counts (1200 pulses, with the two interrupts) requires 1.2 million" - we only use 1 interrupt for the encoder - can you please also double-check that you're converting RPM to RPS when calculating?

Thanks!

digiexchris, 2023-12-15:
it's always missed pulses. And quite a measurable amount. as much as 50 pulses per rev in some cases, judging by how off the next pass is, and because it's incremental it accumulates. I have checked with an RF (1ghz) pulse counter right at the encoder, and all pulses are accounted for, so it's not a mechanical issue.

40us per interrupt with the arduino abstraction. 1000000 microseconds in 1 second. 1000000/40 = 25,000 interrupts in 1 second maximum.
10000 rpm is 166.66 rps. with a 600CPR encoder, (166*600) that's going to need 100,000 interrupts per second. So I was wrong using 1200 instead of 600, but we're still over budget by a factor of 4 for 10k.

25,000 interrupts per second / 600 CPR = 41 RPS, * 60 = 2460 rpm maximum with an otherwise completely idle core and no delay for locks. And considering for reliable sampling the sample speed should be at least 4x the wave form being sampled (if we're talking oscilloscopes and logic probes, anyway), you can see what I'm getting at,

However, this doesn't explain how I lose a bunch of pulses even at 300 rpm. I haven't had a chance to crack out the good RF measuring gear yet and take a look at what the waveform at the MCU pin looks like yet, but I plan to do that next week. Cable lengths and things like that will contribute as well.

Differential signals would eliminate common mode noise, but wouldn't do anything about rise time or other causes of missed pulses. You'd need a third signal to determine which of the two is the correct one. Best we could do is reject common mode noise, and determine that a particular pulse is ambiguous. Differential signals can be very important for long distances in high noise environments, but I'm using proper full shield single side grounded cabling. I will do some common mode measurements anyway just in case.

Considering Mach3 does threading with a single index pulse and no other spindle information, I wonder if I could get away with a 36CPR made out of simple hall effect sensors with the assumption that I only do threading with the spindle running and not moving too slowly.

digiexchris, 2024-01-04:
I'm closing this for now, I've decided to go with another approach, the pcnt periferal is designed to count pulses, and does it's own interrupt handling. I've also started playing with dedicated hardware quadrature encoder counters, I may make an SPI attachment using an stm32 so nanoels can query counts as needed without it needing to use interrupts at all. I'll put Z signal encoding and rollover management in the stm32 as well.  The nice thing about the stm32f1's quadrature decoder is it has built in jitter management.

Closed 2024-01-04.

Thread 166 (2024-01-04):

Fitting to WM180

Colinsp, 2024-01-04:
I am planning on fitting this to the WM180 lathe. The cross slide is identical so there is no issue there. However, the lathe spindle has a gear with only 40 teeth for the encoder. As a result neither this or the alternative gear wheels are suitable. Do you have suggestions for a suitable alternative please?

kachurovskiy, 2024-01-04:
Hi @Colinsp, can you please post some pictures of the relevant pieces of your lathe? Dimensions would also be helpful 👍

Colinsp, 2024-01-05:
The photo shows the headstock end of my lathe with the change gears removed so you can see more. I hope this helps.

kachurovskiy, 2024-01-05:
Got it. Can you give me A and B dimensions?

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

Colinsp, 2024-01-05:
I am not sure what you mean  by A from your drawing. If it is the diameter of the 40 tooth gear it is 42mm.

B is 23mm.
Thanks Colin

kachurovskiy, 2024-01-05:
Just recalled that this was already solved before in https://github.com/kachurovskiy/nanoels/discussions/159 - let's follow-up there.

Closed 2024-01-06.

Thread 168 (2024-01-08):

[Feature Request] Support thread cutting in Gcode

Festivejelly, 2024-01-08:
I've been using the Nano ELS via the gcode function more and more and I think it would be nice to support threading operations through it.

Since we cant set the speed of the spindle in gcode we could instead read the RPM and adjust the feedrate as needed.

So something like G32 Z15.0 would need to work out a base feedrate and adjust that based on the RPM. I guess you did something similar with the automatic threading function on the controller.

Ive made quite a bit of progress on the Ui im building so it would be nice to have this function there.

Festivejelly, 2025-03-02:
Ive implemented this in my fork you can see an example here:

https://github.com/Festivejelly/nanoels/blob/main/h4/h4.ino#L3387C1-L3387C40

Im currently still developing it and its not fully tested yet. But it essentially uses the built in threading function for the controller. But allows us to set the values using gcode.

// G33 Threading command handler
// Format: G33 Z[end] X[end] P[pitch] H[passes] Q[start_z] R[start_x]
// Parameters:
//   Z - End Z position
//   X - End X position
//   P - Thread pitch in mm
//   H - Number of passes (optional, default 3)
//   Q - Start Z position (optional, defaults to current position)
//   R - Start X position (optional, defaults to current position)
// Example: G33 Z20 X-4.188 P1.5 H4 Q0 R-5 - External M10x1.5 thread
// Example: G33 Z20 X-5.1 P1.5 H4 Q0 R-4.5 - Internal M10x1.5 thread

kachurovskiy, 2025-03-02:
That's pretty hacky but if it works it works 🤷

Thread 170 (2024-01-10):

Speed display

duebelpapst, 2024-01-10:
Hello Maxim,

I have noticed that sometimes 0 rpm is displayed for the speed, but when I switch to angle, the angle is displayed correctly and the thread cutting also works.
So it can't be the encoder, do you have an explanation?

Regards,
Stefan

kachurovskiy, 2024-01-10:
Hi Stefan, RPM calculation averages over multiple readings and requires a short period of time to get established when you turn on the RPM display.

We only calculate RPM when it's needed - https://github.com/kachurovskiy/nanoels/blob/4e57cae627a4846d0f2991b280499fa76635bc59/h4/h4.ino#L3018 - to save processing time since it runs on the main thread which also runs the steppers.

If you want, you can change that condition to always calculate it - this way there will be no delay when turned on.

duebelpapst, 2024-01-10:
Thank's, that's what I guess, but I just wanted to ask to be sure.

Regards,
Stefan

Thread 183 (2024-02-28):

Facing and Cut-off issues

lorandzt, 2024-02-28:
Hi Maxim,
The X axis when is controlled by the rotation of the spindle ( facing or cutoff) moves the cross-slide about 2/3 of what should per spindle rotation. The return movement, moving the cross-slide with the arrows is OK. No issues with Z axis, turning works well.

For example, if I do facing in 1 steps on 20mm diameter, the cross-slide (X axis) moves 6.29mm instead of 10mm then returns 10mm.
On the X axis I use the DM556Y motor driver and is set for 800 steps. I have the 1:3 belt drive connection to the cross-slide screw that has 1mm pitch.

Not sure if there is a correlation error between the encoder and the X axis movement or I'm
doing something wrong.
Let me know what you think.
Thank you,
Lorand

kachurovskiy, 2024-02-28:
Hi @lorandzt, sorry to hear that you're facing this issue. If it would help if you could share a video of the problem and maybe a few photos of your build.

1. Do you get insufficient X axis movement when using manual move buttons as well?
2. Please try swapping X and Z terminals on the back of H4. Does the problem now happen on Z axis or remains on X?
3. Please try reducing start speed and acceleration on X axis by 30% and see if it helps.

Thanks!

lorandzt, 2024-02-28:
Hi Maxim,
Weirdly, using manual movement from the buttons was working well for all axis.
I swapped the X and Z terminals and it worked ok so I replaced the DM556Y motor controller with a DM556 and now is working just fine.
Originally I bought two DM556Y for this project and it turned out that both are malfunctioning. I had to replace the original Z axis driver because the stepper was constantly stalling.
I attached couple of pictures.

Thanks for your help,
Lorand

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

Closed 2024-03-01.

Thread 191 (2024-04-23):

some doubts regarding the project

serlancelot, 2024-04-23:
hello!  I have seen your ELS project and I have some doubts...  and I would like if you can answer them before I start buying the components.

The first is the use of a 4-layer PCB, is this for any specific reason?  (signal shielding?) Can only two layers be used?

The second is if you have thought about or are going to put a color LCD screen with graphics, in that case could the same PCB be used or would it be new?

Thank you very much for creating this project!!

kachurovskiy, 2024-04-23:
I'm using 4 layers because at large quantities the cost difference is marginal and signal shielding is noticeably better giving better chances during regulatory compliance tests.

It's a good idea to go with just 2 layer for just a small personal run. You could also get rid of a lot of optional components like filters, fuses, ferrites etc.

I've thought about using a more elaborate LCD but that would make the project MUCH more complicated. Currently the entire thing fits in 1 file, 3k LoC. It's easy to understand and change. Fancy LCD logic will require 3rd party software and much more file/code complexity.

Thanks!

mfxpyro1, 2024-06-23:
You can also remove the 5v to 3v3 converters as the ESP32 inputs are fully 5v tolerant.

kachurovskiy, 2024-06-24:
> You can also remove the 5v to 3v3 converters as the ESP32 inputs are fully 5v tolerant and pretty much any 5v logic input will work fine with 3V3.

It's not 5V tolerant, https://www.espressif.com/sites/default/files/documentation/esp32-s3-wroom-1_wroom-1u_datasheet_en.pdf page 17

It's likely that ESP32 inputs won't immediately fry with 5V inputs (encoder) but we still need to output 5V on most signal pins to drive the stepper motor drivers which for the most parts require 5V to work.

mfxpyro1, 2024-06-24:
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

The CEO of Espressif has gone on record to say despite what that document says the pins ARE 5v tolerant only the power isn't, I've regularly used 3v3 for step/direction driver inputs as they're virtually also opto isolated and the LED's have a reasonable wide input range.

https://voodoo.business/2021/05/19/are-the-esp32-and-esp8266-5v-tolerant-yes-they-officially-are/

"When asked why this information is not in the datasheet, he responded
“the reason is too many users took it to mean that the chip is 5 V tolerant. When we say 5 V tolerant, we are only referring to the IOs. So some users mistook this to make that they can power the chip entirely off the 5 V supply. The correct usage is to use 5 V open for these 5 V tolerant pins, and only via only drain configuration.” And then elaborated on the matter with “I understand, but the time needed to do the iterations when mistakes were made, was too long. when the product was launched 5 V WiFi modules (with DCDC) were the norm. Many users saw “5 V” written in the specs and thought it could be a 1-1 replacement for such modules.”

mfxpyro1, 2024-06-26:
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

I've just built one on prototyping board (Vero/Perf board) including the keypad so about as basic as you can get, it uses an off the shelf ESP32 dev board module and an Adafruit module for the key scanning, case and keypad will be fully 3D printed, not as pretty as the original design but a lot cheaper and just as functional, as I mentioned in my other comment I left out the 5v-3v3 converters as IME they are unnecessary in 99.9% of cases I also left out most of the filtering etc. parts which are needed for a commercial product but not strictly needed for a hobby build..

kachurovskiy, 2024-06-26:
@mfxpyro1 very nice, please kindly post any relevant photos and schematics here for others to use if you can. Thanks 🙏

mfxpyro1, 2024-06-27:
Thanks I will but it'll take a little while as I'm redoing the keypad for larger buttons which also means a new case.

mfxpyro1, 2024-07-03:
> @mfxpyro1 very nice, please kindly post any relevant photos and schematics here for others to use if you can. Thanks 🙏

Here you go, hope it works.

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

RGUERI1, 2025-02-21:
Very well done.

demsarmatjaz, 2025-02-22:
Great job @mfxpyro1. I wonder how did you implement I2C keypad? That is exactly what I am looking for.

mfxpyro1, 2025-02-22:
Same as the original but IC is pre soldered onto a breakout board, it was
bought from Amazon, keypad was "bodge wired" on matrix board and everything
else 3D printed.

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

demsarmatjaz, 2025-02-23:
Thanks for the answer. I probably phrased the question a bit incorrectly... I know you used the Adafruit circuit with the TCA8418 encoder, the question was more in terms of how you modified the code to read the keyboard via the I2C protocol, not the serial one, which the original code uses?

mfxpyro1, 2025-02-23:
I didn't modify the code it works exactly the same way as the original.

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

demsarmatjaz, 2025-02-23:
ah, of course, how stupid I am... this is the H4 version and not the H5. The H4 basically works with the TCA8418.

richoffpints, 2025-04-14:
did this h4 work?

richoffpints, 2025-04-14:
@mfxpyro1

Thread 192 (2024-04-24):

RPM gets stuck sometimes

digiexchris, 2024-04-24:
Hi, I'm not quite sure under what circumstances this happens, but sometimes my RPM display gets stuck. It shows 0 rpm when stopped, and when running it goes to the last set RPM, even if I change rpm. It stops updating. I need to power cycle the system to get it to respond again.

Is this a known issue?

kachurovskiy, 2024-04-24:
Hi Chris, seems like a new issue.

I guess the condition at https://github.com/kachurovskiy/nanoels/blob/main/h4/h4.ino#L580 is not overflow-proof.

Try replacing the first 2 conditions in that function with the following and let me know if that helps?

```
unsigned long t = micros();
unsigned long elapsedTime = t - spindleEncTime;
if (elapsedTime > 50000) {
  // RPM less than 10.
  spindleEncTimeDiffBulk = 0;
  return 0;
}
if (elapsedTime < RPM_UPDATE_INTERVAL_MICROS) {
  // Don't update RPM too often to avoid flickering.
  return shownRpm;
}
```

digiexchris, 2024-04-26:
sure I'll give that a try. I'm planning on putting a different encoder on in a few days, I'll do it then.

vegetate7, 2024-05-02:
Hello! Maxim, I'll try you fixes tomorrow. But. I think it may be not only RPM display issue. I saw same time axis moving stopped. Either automatic and manual (showing "SYNC" on display). Like it losing a sync to spindle encoder. But same time angle display still working correctly.

kachurovskiy, 2024-05-02:
It's possible for the lead screw to go out of sync with the spindle by removing the limit while the carriage is standing on it. It's indicated by the SYN word on the display.

This situation should resolve itself once the spindle makes a full turn, mode changes or the stop button is pressed.

vegetate7, 2024-05-02:
> @vegetate7 it's possible for the lead screw to go out of sync with the spindle by removing the limit while the carriage is standing on it. It's indicated by the SYN word on the display.
>
> This situation should resolve itself once the spindle makes a full turn, mode changes or the stop button is pressed.

But it is not this case. When RPM stops, i can not move carriage by arrow buttons. The stepper start humming, and no moving (I have "need rest" option enabled). This state only can be disabled by powercycle. Or by pressing "stop" button, and powercycle after it because "Stop in manual mode".
Auto modes can not be started too. Again, stepper start hummin, display shows "step 0", carriage not moving.
Twise i have this issue in the middle of turn pass: carriage stopped and no moving after.
The spindle keep rotating in all those cases.
So IMO something wrong in the "processSpindleCounter()". I planned to look closer, but had no time yet.

kachurovskiy, 2024-05-03:
@vegetate7 that sounds like a separate issue we should look into. Please file a new issue with the steps to reproduce if you can

vegetate7, 2024-05-03:
> @vegetate7 that sounds like a separate issue we should look into. Please file a new issue with the steps to reproduce if you can

Ok, I'll do it later.
WRT proposed changes: It shold be ok, I do not see why not. But it completely stops to count RPM. Suppose it should be something very obviouse :) Can not look closer, It's machining right now..

vegetate7, 2024-05-03:
> > @vegetate7 that sounds like a separate issue we should look into. Please file a new issue with the steps to reproduce if you can
>
> Ok, I'll do it later. WRT proposed changes: It shold be ok, I do not see why not. But it completely stops to count RPM. Suppose it should be something very obviouse :) Can not look closer, It's machining right now..

ah.. I think it's here:
`
...
  if (elapsedTime < RPM_UPDATE_INTERVAL_MICROS) {
...
`
'elapsedTime' should be rebased to 'showRpmTime' first:
`
....
  unsigned long elapsedTime = t - showRpmTime;
  if (elapsedTime < RPM_UPDATE_INTERVAL_MICROS) {
...
`

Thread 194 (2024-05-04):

Carriage stops moving

vegetate7, 2024-05-04:
Sometimes the carriage stops moving. Auto modes no starting (shows "step 0"). Manual moves not starting too. It just start humming by stepper, but no move. I'm using "need rest" option, so steppers disabled at idle.
Hard to tell how to reproduce. Like make some moves, and then keep system powered on for long time (1hr 11 min, i guess :) without steppers activity).
I think it's here it not overflow-proof. Not sure, tho, is it only my branch affected, or the main too.
in the `void moveAxis(Axis* a)`
my branch:
```
...
  unsigned long nowUs = micros();
  float delayUs = 1000000.0 / a->speed;
  if ((nowUs - a->stepStartUs < delayUs - 5)||
      ((a->posByDRO && a->backlashByDRO && a->needsDROBacklashCompensation) &&
       (a->stepStartUs + DRO_READ_PERIOD_MS * 1000 > nowUs)) ){
    // Not enough time has passed to issue this step.
    return;
  }
 ...
```
main:
```
...
  unsigned long nowUs = micros();
  float delayUs = 1000000.0 / a->speed;
  if (nowUs - a->stepStartUs < delayUs - 5) {
    // Not enough time has passed to issue this step.
    return;
  }
...
```

micros() rotating aroung 1hr 11min, so if last 'stepStartUs' taken too long ago, it can became significantly bigger then 'nowUs'.
I suppose both branches may be affected, but I'm not very good in the overflow handle programmin. If it only mine, I'll be glad to have some advices how to fix.

kachurovskiy, 2024-05-04:
Hi @vegetate7, thanks for reporting this.

1. Can you please take a photo of the screen next time this happens?
2. Can you please attach your h4.ino with your next comment or share it via https://gist.github.com/?
3. I'm not aware of the way to get into the `step 0` state - it doesn't accept 0 values - do you know how to do that?

Thanks!

vegetate7, 2024-05-04:
My h4.ino: https://github.com/vegetate7/nanoels_dro/blob/main/h4/h4.ino
Just looked at the code, not the 'step 0', but actually 'Pass 0 of ...', I just wrongly remembered, sorry :)
Not going to machining right now, so can not take photo.
But I had a time to play with code. I thing it's a bit of "silent type conversion" magic, and this:
```
  if ((nowUs - a->stepStartUs < delayUs - 5)||
      ((a->posByDRO && a->backlashByDRO && a->needsDROBacklashCompensation) &&
       (a->stepStartUs + DRO_READ_PERIOD_MS * 1000 > nowUs)) ){
    // Not enough time has passed to issue this step.
    return;
  }
```
should be done as this:
```
  if ((nowUs - a->stepStartUs < delayUs - 5)||
      ((a->posByDRO && a->backlashByDRO && a->needsDROBacklashCompensation) &&
       (nowUs - a->stepStartUs < DRO_READ_PERIOD_MS * 1000)) ){
    // Not enough time has passed to issue this step.
    return;
  }
```
Your code is already OK here. IMO. I'll try it a bit later.

kachurovskiy, 2024-05-04:
Could it be that you switched to spindle reverse and forgot to switch back? This is the usual cause of automatic operations not starting.

vegetate7, 2024-05-04:
Nope. I usually starting operations when spindle already running. I'll test my fix in few days, just not right now.

vegetate7, 2024-06-29:
Well, I had a chance to test. Yes, type conversion trick fixes issue. I'll close this one.

Closed 2024-06-29.

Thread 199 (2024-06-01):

error: too many arguments to function 'hw_timer_t*

atmelletje, 2024-06-01:
hello Maxim,

I have some issues getting the ESP32 programmed.
IDE 2.3.2
updated and installed the ESP32 boards including the Adafruit lib.
I'm fairly new to programming such devices. would be nice if you could push me in the right direction.

h4\h4.ino:570:37: error: too many arguments to function 'hw_timer_t* timerBegin(uint32_t)'
  570 | hw_timer_t *async_timer = timerBegin(0, 80, true);
      |                           ~~~~~~~~~~^~~~~~~~~~~~~
 'hw_timer_t* timerBegin(uint32_t)'

Roel

kachurovskiy, 2024-06-01:
Hi @atmelletje, not sure, try changing your esp32 library version to 2.0? https://github.com/espressif/arduino-esp32/issues/8765#issuecomment-1867399333

atmelletje, 2024-06-02:
hello Maxim, first of all, thank you for your fast reply.
what I did is the following workaround,
I went back to Arduino v1.8.18 and installed the  Espressif esp32 v2.0.17
That worked like a Champ.

Danke Maxim,

Roel

jherbert7621, 2024-06-20:
Hi @atmelletje,
had the same issue, as Maxim suggested changing esp32 library to 2.0 does the trick!
Juergen

atmelletje, 2024-06-21:
it works great, I have some boards left over. they are completely assembled and working. drop me a message if someone needs one! a complete set is also possible. next to replace are the leadscrews with some decent ballscrew spindles.

kachurovskiy, 2024-08-29:
This should now be resolved thanks to https://github.com/kachurovskiy/nanoels/commit/f0e5ebeef747257782caa141d6bcb181ce0b972a

Closed 2024-08-29.

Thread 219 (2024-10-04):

H2 build report

leehambley, 2024-10-04:
I started on a H2 build more than a year ago, but due to incompatibility between my lathe housing, and the H2 enclosure I stalled for a while, also I rarely/never use my lathe and I didn't need to hurry. As a new owner of a Bambu X1, and having relearned FreeCAD after their 1.0 RC I decided to finish off the build.

The machine is a Optimum TU 2406 V - Vario; it's probably not dissimilar to any other asia-made lathe, however being a _vario_ (variable speed) it had some decent built-in electronics with a 5, and 9v supply on the power board.

I was able to mount the stepper motor below the lead screw, under the fascia using 1:1 ratio gears which I custom printed. I would like to change this for 1:3 pulleys so I get more torque, but the 3d printed gears (with a filed-in keyway) work basically fine for now, however they are noisy due to not running perfectly round.

I originally had a Honeywell DIN rail 5, and 24v power supply in an electrical enclosure below the lathe, however I couldn't source a single cabinet large enough to house the comically-large 24v din rail power supply. I had an inexpensive no-name 24v/3.5A DC supply which came with some CNC kit I never used hanging around. This 24v PSU fits inside the side cover where the belt-drive and is conveniently close to where the main power switch.etc exist.

For the 5v, the machine's built-in tachometer already had 5v, which I tapped and used to power the Arduino.

Attached a bunch of pics, I hope someone gets some benefit from this thread.

Edit to add: the freecad files in the h2 directory seem to be an older version than the stls in the h2 directory; I stumbled over this and modified the printed case directly with a finger sander.

Edit again to add: the hand-drawn labels are actually 3d-printed into the case, but I had such a hard time to model the icons and project the geometry to have neat icons, that I gave up and hand-drew them in the slicer.

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

Closed 2024-10-04.

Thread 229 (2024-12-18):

Contar las vueltas del husillo

tektonandroid, 2024-12-18:
Buenas tardes a todos. Quisiera utilizar mi torno para contar las vueltas al bobinar transformadores. ¿sería posible implementar un contador de vueltas en el software del h4?
saludos y gracias

tektonandroid, 2024-12-20:
No va en Issues

Closed 2024-12-20.

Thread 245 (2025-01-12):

H5 Compile Error

AlanMerry, 2025-01-12:
I was attempting to upload the h5.ino file to the controller but got this error:-

C:\Users\alann\OneDrive\Documents\3DPrinterProjects\ELSBuild\nanoels-main\h5\h5.ino: In function 'void setup()':
C:\Users\alann\OneDrive\Documents\3DPrinterProjects\ELSBuild\nanoels-main\h5\h5.ino:1425:13: error: 'A12' was not declared in this scope; did you mean 'A2'?
 1425 |     pinMode(A12, OUTPUT);
      |             ^~~
      |             A2
C:\Users\alann\OneDrive\Documents\3DPrinterProjects\ELSBuild\nanoels-main\h5\h5.ino:1426:13: error: 'A13' was not declared in this scope; did you mean 'A3'?
 1426 |     pinMode(A13, OUTPUT);
      |             ^~~
      |             A3
C:\Users\alann\OneDrive\Documents\3DPrinterProjects\ELSBuild\nanoels-main\h5\h5.ino:1427:13: error: 'A11' was not declared in this scope; did you mean 'B11'?
 1427 |     pinMode(A11, OUTPUT);
      |             ^~~
      |             B11
C:\Users\alann\OneDrive\Documents\3DPrinterProjects\ELSBuild\nanoels-main\h5\h5.ino:1440:179: error: 'A11' was not declared in this scope; did you mean 'B11'?
 1440 |   initAxis(&y, NAME_Y, ACTIVE_Y, ROTARY_Y, MOTOR_STEPS_Y, SCREW_Y_DU, SPEED_START_Y, SPEED_MANUAL_MOVE_Y, ACCELERATION_Y, INVERT_Y, NEEDS_REST_Y, MAX_TRAVEL_MM_Y, BACKLASH_DU_Y, A11, A12, A13, Y_PULSE_A, Y_PULSE_B, PCNT_UNIT_3);
      |                                                                                                                                                                                   ^~~
      |                                                                                                                                                                                   B11
C:\Users\alann\OneDrive\Documents\3DPrinterProjects\ELSBuild\nanoels-main\h5\h5.ino:1440:184: error: 'A12' was not declared in this scope; did you mean 'A2'?
 1440 |   initAxis(&y, NAME_Y, ACTIVE_Y, ROTARY_Y, MOTOR_STEPS_Y, SCREW_Y_DU, SPEED_START_Y, SPEED_MANUAL_MOVE_Y, ACCELERATION_Y, INVERT_Y, NEEDS_REST_Y, MAX_TRAVEL_MM_Y, BACKLASH_DU_Y, A11, A12, A13, Y_PULSE_A, Y_PULSE_B, PCNT_UNIT_3);
      |                                                                                                                                                                                        ^~~
      |                                                                                                                                                                                        A2
C:\Users\alann\OneDrive\Documents\3DPrinterProjects\ELSBuild\nanoels-main\h5\h5.ino:1440:189: error: 'A13' was not declared in this scope; did you mean 'A3'?
 1440 |   initAxis(&y, NAME_Y, ACTIVE_Y, ROTARY_Y, MOTOR_STEPS_Y, SCREW_Y_DU, SPEED_START_Y, SPEED_MANUAL_MOVE_Y, ACCELERATION_Y, INVERT_Y, NEEDS_REST_Y, MAX_TRAVEL_MM_Y, BACKLASH_DU_Y, A11, A12, A13, Y_PULSE_A, Y_PULSE_B, PCNT_UNIT_3);
      |                                                                                                                                                                                             ^~~
      |                                                                                                                                                                                             A3

exit status 1

Compilation error: 'A12' was not declared in this scope; did you mean 'A2'?

kachurovskiy, 2025-01-12:
@AlanMerry weird how it even compiles for most of us. Fixed in https://github.com/kachurovskiy/nanoels/commit/65d622a9ad9edec2793c18dfa00d603a79a59bb0 - thanks for reporting.

AlanMerry, 2025-01-12:
Thank you Maxim, it has now compiled successfully and I have now uploaded to the controller.

Closed 2025-01-13.

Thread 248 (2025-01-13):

H5 Disable/Enable Z Axis Button

AlanMerry, 2025-01-13:
In the description of keys there is "<>| button left of Z disables / enables Z axis"

This does not appear to work.

The button to the left of my Z key is the shift key.

kachurovskiy, 2025-01-13:
Yeah, I guess some keyboards don't have this key.

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

Perhaps you could map it to Shift or some other key of convenience? Keys are somewhat randomly assigned now, open to suggestions there.

AlanMerry, 2025-01-13:
Not sure that shift would work, it normally modifies another key I think. What about the x key

Closed 2025-01-13.

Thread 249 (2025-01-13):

H5 Limit buttons

AlanMerry, 2025-01-13:
I am wondering what keys are assigned to the limit setting as per the h4 special keys.

kachurovskiy, 2025-01-13:
As per https://github.com/kachurovskiy/nanoels/tree/main/h5#usage-manual `A W D S control limits` - do those keys not work for you?

AlanMerry, 2025-01-13:
My apologies, I realised that I had not picked up those keys after I raised this issue. Yes, those keys work.

Closed 2025-01-13.

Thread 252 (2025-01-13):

H5 async mode broken

kachurovskiy, 2025-01-13:
Even though there are no changes to the ASYNC code, in H5 it doesn't move the axes at all.

kachurovskiy, 2025-06-04:
https://g.co/gemini/share/d6529ef57fac

Changing `timerBegin()` call to `hw_timer_t *async_timer = timerBegin(0, 80, true);` doesn't compile of course but I think the diagnosis is correct - https://docs.espressif.com/projects/arduino-esp32/en/latest/api/timer.html#timerbegin - we're getting NULL from `timerBegin()`. Question is what to do about it 🤔

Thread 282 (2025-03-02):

Is this Project DEAD?????

ronehorn, 2025-03-02:
Even though there are no changes to the ASYNC code, in H5 it doesn't move the axes at all. I have purchased the boards for this project but want to know if this issue will be fixed.  I need a control for a lathe that cuts threads??

kachurovskiy, 2025-03-02:
Hi @ronehorn, yes there's some problem with timers, didn't look into it yet. What are you using async mode for?

ronehorn, 2025-03-03:
I need the threading function ... for a lathe

Closed 2025-03-13.

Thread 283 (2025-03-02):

Movement rough via Gcode but smooth via controller

Festivejelly, 2025-03-02:
I'm noticing that when moving the axis using the directional buttons on the Z the movement is nice and smooth.

But when sending fast commands by gcode its quite jerky. Even though technically the feedrate is lower.

I suspect this is the culprit:

long chunks = round(max(max(abs(xDiff), abs(zDiff)), abs(a1Diff)) * LINEAR_INTERPOLATION_PRECISION);
for (long i = 0; i < chunks; i++) {
    if (!isOn) return;
    float scale = i / float(chunks);
    stepToContinuous(&x, xStart + xDiff * scale);
    stepToContinuous(&z, zStart + zDiff * scale);
    if (ACTIVE_A1) stepToContinuous(&a1, a1Start + a1Diff * scale);
    gcodeWaitNear();
}

I didnt notice it before when I was running much slower speeds. But now im running with ballscrews im pushing it a bit faster.

I think maybe using velocity planning rather than chunking would result in a smoother move and probably a better finish.

I'll have a crack at implementing this, just wanted to raise the issue to track it but also see if there any alternative solutions.

kachurovskiy, 2025-03-02:
Can you give an example GCode where the movement is jerky and share video of the problem?

Festivejelly, 2025-03-02:
If I send G1 Z30 F800 its a bit jerky.

Anything up to 500 seems to be fine.

Ill take a video next time im in my workshop. You cant really see it jerking, you can just feel it and hear it.

kachurovskiy, 2025-04-14:
> the movement remains jerky

Is it jerky at the start, end, or all the way through at equal intervals?

> Maybe I can tweak these values?

Sure, give it a try

Festivejelly, 2025-04-15:
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

Its jerky the entire movement.

So lets say I do Z10 F800 its very jerky, or maybe more accurately it kinda vibrates.

The faster the feedrate the more kind vibrates.

I cant get near the jog speed of the manual controls without it vibrating too much.

kachurovskiy, 2025-04-15:
I think this is caused by using high number of steps per revolution and `GCODE_WAIT_EPSILON_STEPS` being just a constant 10. Try increasing it to e.g. 50 and seeing if it helps.

Festivejelly, 2025-04-15:
> I think this is caused by using high number of steps per revolution and `GCODE_WAIT_EPSILON_STEPS` being just a constant 10. Try increasing it to e.g. 50 and seeing if it helps.

Ill try that.

What would be the downside of not moving in chunks? Its not clear why the movements are done in chunks for gcode. Is it so we can send stop commands?

For example:

// Rapid positioning / linear interpolation.
void G00_01(const String& command) {
  long xStart = x.pos;
  long zStart = z.pos;
  long a1Start = a1.pos;
  long xEnd = command.indexOf(x.name) >= 0 ? mmOrInchToAbsolutePos(&x, getFloat(command, x.name)) : xStart;
  long zEnd = command.indexOf(z.name) >= 0 ? mmOrInchToAbsolutePos(&z, getFloat(command, z.name)) : zStart;
  long a1End = command.indexOf(a1.name) >= 0 ? mmOrInchToAbsolutePos(&a1, getFloat(command, a1.name)) : a1Start;
  long xDiff = xEnd - xStart;
  long zDiff = zEnd - zStart;
  long a1Diff = a1End - a1Start;

  // Calculate required speeds for coordinated movement
  updateAxisSpeeds(xDiff, zDiff, a1Diff);

  // Command axes to move directly to the final position
  // The underlying stepTo/moveAxis logic should handle smooth motion
  stepToFinal(&x, xEnd);
  stepToFinal(&z, zEnd);
  if (ACTIVE_A1) stepToFinal(&a1, a1End);

  // Wait for the entire move to complete
  gcodeWaitStop();
}

Festivejelly, 2025-04-15:
> Yes, IIRC the main reason is being able to stop when the spindle stops or a stop command is issued via keyboard or other means.

So could we do something like this instead?

void gcodeWaitEpsilon(int epsilon) {
  while ((abs(x.pendingPos) > epsilon ||
          abs(z.pendingPos) > epsilon ||
          abs(a1.pendingPos) > epsilon ||
          (SPINDLE_PAUSES_GCODE && getApproxRpm() < GCODE_MIN_RPM)) && isOn) {
    taskYIELD();
  }

  // If motion was cancelled (isOn is false either from the controller button or via sending the the stop command by gcode)
  if (!isOn) {
    if (xSemaphoreTake(motionMutex, 100) == pdTRUE) {
      x.pendingPos = 0;
      z.pendingPos = 0;
      if (ACTIVE_A1) a1.pendingPos = 0;
      xSemaphoreGive(motionMutex);
    }
  }
}

kachurovskiy, 2025-04-15:
I would not advise that, try playing with `GCODE_WAIT_EPSILON_STEPS`.

Festivejelly, 2025-04-16:
> I would not advise that, try playing with `GCODE_WAIT_EPSILON_STEPS`.

I did make the change... because well... im a cowboy haha. What are the risks of me using my code? It seems to still react to stop commands.

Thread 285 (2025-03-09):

H4 - real stepmotor  off function.

RobinI30N, 2025-03-09:
I made my own compilation ver. H4. I changed the LCD to I2C and the QWERTY I2C keyboard.
https://docs.m5stack.com/en/unit/cardkb_1.1

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

I had a problem with manual movement from the keyboard: if I move the axis it moves infinitely.
I noticed that the keyboard handling thread during movement is not handled - the key release code is not read. The solution was - I don't know if it's correct? - but it works:

void taskDisplay(void *param) {
  while (emergencyStop == ESTOP_NONE) {
    updateDisplay();
    processKeypadEvent();   <------------------------

I also want to turn off the engine (release the ENA signal): if I turn off a given axis on the display, it will allow manual movement of the lathe wheels.
Could you give me some advice on how to achieve this?

kachurovskiy, 2025-03-09:
Manual movement and keyboard handling is indeed on the same core (https://github.com/kachurovskiy/nanoels/blob/main/h4/h4.ino#L1754-L1757) but e.g. taskMoveZ() yields by calling `waitForPendingPosNear0()`. I'm not sure why calling `processKeypadEvent()` from another thread on the same core would make a difference.

You can auto-disable axes when they aren't moving via `NEEDS_REST_Z` and `NEEDS_REST_X` configuration params or use the respective buttons to control this yourself - https://github.com/kachurovskiy/nanoels/blob/main/h4/h4.ino#L2568-L2573

RobinI30N, 2025-03-09:
Thanks for the tip.
1. Could it be a problem that the LCD and keyboard are the same I2C bus?

2. There is a function in the code that does this.

void updateEnable(Axis* a) {
  if (!a->disabled && (!a->needsRest || a->stepperEnableCounter > 0)) {
    DHIGH(a->ena);
    // Stepper driver needs some time before it will react to pulses.
    DELAY(STEPPED_ENABLE_DELAY_MS);
  } else {
    DLOW(a->ena);
  }
}

GPIO state is changing, now I know I have an electrical problem with the controller

Thank you

RobinI30N, 2025-03-15:
appreciate the amount of work you put into the software.

However, when all the code is in one file, analysis is very difficult.

I am looking for a place in the code to change the movement distance per one movement encoder pulse.

It would be natural for one pulse to move the axis by 0.01, instead of 0.015.

The wheel has 100/ppr.

kachurovskiy, 2025-03-15:
Imagine how difficult it would be for you with 25 files in 4 folders :) With 1 file you can at least search or scroll.

Just increase `PULSE_PER_REVOLUTION` in https://github.com/kachurovskiy/nanoels/blob/main/h4/h4.ino#L65C13-L65C34 by 33%

RobinI30N, 2025-03-15:
With a 100 pulse wheel, I had PULSE_PER_REVOLUTION = 100 entered.
After changing to PULSE_PER_REVOLUTION = 150 I have 0.01mm/p - I would never have discovered that.

For now I did it for the Z axis, I don't know how it will affect the X axis :)

RobinI30N, 2025-04-04:
I re-ran the changes with custom LCD and keyboard customization on a clean h4v12 file and the keyboard thread problem disappeared. I didn't check what was wrong before.

Closed 2025-04-04.

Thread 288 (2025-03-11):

web interface to control the H5 system's operation？

ningjiazun, 2025-03-11:
Have you considered implementing a web interface to control the H5 system's operation, similar to how you currently manage G-code via a web interface? This would allow you to leverage existing devices (e.g., smartphones, tablets, or computers) as control screens, eliminating the need for dedicated hardware. You could reference Duet3D's DuetWebControl (a web-based control system for 3D printers) for design inspiration and functional implementation.

kotovasia5120, 2025-03-11:
Yes of course this is in the plans.

kachurovskiy, 2025-03-11:
@kotovasia5120 would it make sense to keep this issue open for tracking purposes?

kotovasia5120, 2025-03-11:
> @kotovasia5120 would it make sense to keep this issue open for tracking purposes?

🤷‍♂️In such cases, they usually use a division into tags, issues, and feature requests. Decide for yourself.

kachurovskiy, 2025-03-11:
@ningjiazun 3D printer is a bit of a different machine, I run my printer without even looking at it - just send the job over. Stock is always loaded, machine has end stops and auto bed leveling.

With lathe, it's not really possible to do anything remotely - at least with machines NanoEls is aimed at, you have to be at the machine to change the tool, insert the stock, zero the tool, watch it run to adjust the RPM or stop.

Eliminating a 22 EUR keyboard to replace it with a 100 EUR smartphone or tablet that is less good at the job (not tactile) seems strange. Or do you suggest to eliminate the Nextion screen too?

arvin2009, 2025-03-11:
اگرر در این نمایشگر کلید ها طراحی شود خوب  است و گر نه برای نمایش چند خط بسیار گران است

ningjiazun, 2025-03-14:
Implement a web-based control interface to connect the ESP32 board via the local Wi-Fi network, enabling control and monitoring through existing electronic devices. This setup also facilitates seamless OTA  updates in the future.

ningjiazun, 2025-03-14:
Additionally, using the Nextion serial touch screen solely for status display without leveraging its interactive control capabilities seems like underutilization of resources。

Closed 2025-03-11.

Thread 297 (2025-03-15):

Compilation error: too few arguments to function 'hw_timer_t* timerBegin(uint8_t, uint16_t, bool)'

arvin2009, 2025-03-15:
What is the cause of this error in H5?
I searched and it said to download the library platform-espressif32-51.03.03 but it didn't work.

arvin2009, 2025-03-15:
Look here. I did this and the software completely froze and got stuck.
[https://community.platformio.org/t/problem-compiling-code-for-esp32-dev-module/41873](url)

kachurovskiy, 2025-03-16:
Most likely a version problem with one of the libraries of board.

Try backing up your sketches, uninstalling Arduino and installing everything again as per https://github.com/kachurovskiy/nanoels/tree/main/h5#programming-the-controller

arvin2009, 2025-03-16:
I uninstalled and reinstalled several times. The error persists. The problem is here.esp32 boards 2.0.18
The non-valid version 3 must be used. But I couldn't install that either.

arvin2009, 2025-03-16:
What version of IDE are you using?

kachurovskiy, 2025-03-16:
Arduino IDE 2.3.4, esp boards 3.1.3. Looks like you have old version of the esp32 board definitions installed, needs to be updated to 3.x.x.

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

arvin2009, 2025-03-16:
Exactly right. I had the old one installed and didn't see this one. I think it's fixed. Thanks.

Closed 2025-03-20.

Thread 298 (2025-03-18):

элипс

andreev-, 2025-03-18:
когда я ставлю количество импульсов драйвера мотора отличное от 800 , например 25600 то в режиме элипс не получается точное повторение элипса, проверь у тебя так же?

Closed 2025-03-18.

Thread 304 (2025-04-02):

left and right limits is reversed ?

RobinI30N, 2025-04-02:
Last version H4V12.

Hello
I am at the stage of starting and checking.

I have the impression that the meaning of the left and right limits is reversed.
If the symbol >| is displayed, it suggests setting the right limit. The action is such that the carriage stops at the limit moving to the left.

|< works the other way around. Up / down limits works according to the symbol.

The second inconsistency is in Face mode - "left to right" processes the left surface and should take the material moving to the left.

Is there a simple way to adjust this?

I understand that the Z axis has positive values   on the right side - they increase when I move away from the spindle?

kachurovskiy, 2025-04-02:
The long axis on the lathe is usually called Z. In our case we assume that it increments to the left, towards the spindle. Sounds like you need to invert the Z axis motor in the code or on the driver.

RobinI30N, 2025-04-02:
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
Let's systematize, I assumed according to the drawing.
Is there any inconsistency with the NanoELS convention?

RobinI30N, 2025-04-04:
Yes.. that was the cause.
Changing the direction of the Z axis solved this problem..also other unreported ones.

It doesn't matter to me anymore but you could include a drawing of the valid axis directions in the documentation.

Thank you and best regards.

RobinI30N, 2025-04-04:
".. if motor is moving in the wrong direction..,"
Only it is not known which direction is correct - for the author it is obvious.

You can adjust the wheel, keyboard and engine so that the manual movement is consistent, but for the program it is incorrect (my case).

I tried to solve this without assuming inssues from your video and it came out as it did - i.e. the other way around. ;)

RobinI30N, 2025-04-04:
yes.. because the entire project except for the software was mine. Changing the type of keyboard, LCD, schematic and PCB.

I managed to set everything up so that everything worked properly except for the limits.

I immediately ruled out a software error but I hit a wall and ran out of ideas.

That's why I asked on github.

Closed 2025-04-04.

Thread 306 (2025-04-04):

Пользовательская клавиатура

Lagros, 2025-04-04:
У Вас в описании, при использовании своей клавиатуры, чтобы увидеть код нажимаемой клавиши, написано ,что нужно раскомментировать строку 115 (https://github.com/kachurovskiy/nanoels/blob/main/h5/h5.ino#L115).
Или я ошибаюсь, или речь идет о строке 2640   // setText("t0", (isPress ? "Press " : "Release ") + String(keyCode));

kachurovskiy, 2025-04-04:
Спасибо, теперь более понятно написано.

Lagros, 2025-07-27:
В процессе доработки прошивки, ссылки настройки пользовательской клавиатуры на строки сдвигаются. Сейчас интерактивная ссылка переходит к строке 2640, а нужно 3001. Так-же и 121 строка переместилась на 124.

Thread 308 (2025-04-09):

h4

richoffpints, 2025-04-09:
hey so this is my first ime buying and building a pcb from online, i have the folder with the gerber and the bom and pcbs files, can you please give me a step by step on how tob ordder all the components for the h4 boards. i feel like the way im doing it is wrong, i dont wana spend money and cuzim dumb and miss somethung. this is such a great project. litterly iv looked and your makingcrazycoolshit i love it

kachurovskiy, 2025-04-09:
Hi @richoffpints, it's very hard to build H4 because it's a complex PCB and a lot of components specified are no longer available. It's also expensive.

I suggest you build H5 instead, it's much cheaper and easier. Process of ordering the pcbs is described in the 5th version documentation.

richoffpints, 2025-04-09:
can you tell me how i can convert the h5 into a 4axis? is it possible even?

richoffpints, 2025-04-14:
so how do i change the code to use z scale output on  a new axis? is it easy? i know c so u dont need to skid it

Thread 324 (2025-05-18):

PCNT driver error

slapukas, 2025-05-18:
При компиляции выводит сообщение:
#warning "legacy pcnt driver is deprecated, please migrate to use driver/pulse_cnt.h"
при старте
19:54:04.862 -> E (2899) pcnt(legacy): _pcnt_get_counter_value(108): PCNT driver error
19:54:04.896 -> E (2899) pcnt(legacy): _pcnt_get_counter_value(108): PCNT driver error
19:54:04.896 -> E (2899) pcnt(legacy): _pcnt_get_counter_value(108): PCNT driver error
как это устранить????

Arduino IDE 2.3.6 ESP32 v. 3.20

kachurovskiy, 2025-05-20:
Странно, какая у вас версия ESP32? Нужно ESP32-S3 например N16R8.

slapukas, 2025-05-21:
версия N16R8, странно то, что и h4 тоже выдает при старте PCNT driwer error. С ESP IDF 2.17 pcnt.h при компиляции проходит без преупреждения о миграции но  PCNT driver error все равно. Максим, если можно, какие у Вас установки в arduino ide для ESP32S3 N16R8? ИИ (ChatGPT) бредит о возмошности конфликта пинов, нету ни киких конфлитов.

kachurovskiy, 2025-05-21:
Попробуйте отключить дисплей при загрузке прошивки. Насколько я понимаю ваш дисплей сам имеет внутри еще одну ESP32 и подключён к тому же серийному каналу.

slapukas, 2025-05-21:
Эта белеберда выдается и без дисплея, но..... энкодеры работают! С такой конфигурацией PCNT ошибки не дает :

#include "driver/pcnt.h"

#define PCNT_H_LIM    310000
#define PCNT_L_LIM    300000
#define PCNT_FILTER   1  // 1 APB clock cycles (~1 us)

typedef struct {
  pcnt_unit_t unit;
  int gpioA;
  int gpioB;
} EncoderConfig;

EncoderConfig encoders[4] = {
  { PCNT_UNIT_0, 13, 14 },
  { PCNT_UNIT_1, 18, 8 },
  { PCNT_UNIT_2, 47, 21 },
  { PCNT_UNIT_3, 45, 48 }
};

void setupEncoder(const EncoderConfig& config) {
  pcnt_config_t pcntConfig = {};
  pcntConfig.pulse_gpio_num = config.gpioA;
  pcntConfig.ctrl_gpio_num = config.gpioB;
  pcntConfig.channel = PCNT_CHANNEL_0;
  pcntConfig.unit = config.unit;
  pcntConfig.pos_mode = PCNT_COUNT_INC;     // Count on A rising
  pcntConfig.neg_mode = PCNT_COUNT_DEC;     // Count on A falling
  pcntConfig.lctrl_mode = PCNT_MODE_REVERSE;
  pcntConfig.hctrl_mode = PCNT_MODE_KEEP;
  pcntConfig.counter_h_lim = PCNT_H_LIM;
  pcntConfig.counter_l_lim = PCNT_L_LIM;

  pcnt_unit_config(&pcntConfig);
  pcnt_set_filter_value(config.unit, PCNT_FILTER);
  pcnt_filter_enable(config.unit);
  pcnt_counter_pause(config.unit);
  pcnt_counter_clear(config.unit);
  pcnt_counter_resume(config.unit);
}

void setup() {
  Serial.begin(115200);
  delay(1000);
  Serial.println("Starting 3 rotary encoders using PCNT...");

  for (int i = 0; i < 4; i++) {
    setupEncoder(encoders[i]);
  }
}

void loop() {
  for (int i = 0; i < 4; i++) {
    int16_t count = 0;
    esp_err_t err = pcnt_get_counter_value(encoders[i].unit, &count);
    if (err == ESP_OK) {
      Serial.printf("Encoder %d count: %d\n", i + 1, count);
    } else {
      Serial.printf("Encoder %d read error: %d\n", i + 1, err);
    }
  }
  Serial.println("--------------------------");
  delay(1000);
}

kachurovskiy, 2025-05-25:
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

Мне кажется это происходит потому что мы пытаемся прочитать счетчики перед тем как они инициализированы. Попробуйте переставить строку 3335 на 3331 и скажите помогает или нет.

Closed 2025-05-25.

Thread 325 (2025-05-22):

Loss steps

Jjjigu, 2025-05-22:
Thank you so much for sharing the project, it's amazing.
 I've been using the H2 for a year and I'm very happy with it, but I've decided to switch to the H5.  Nema 24 in Z and 17 in X .

I've encountered a problem.
In manual movements ,and in displacement movements without material loading or when threading at high speed,  there is a huge loss of steps that prevents the axes from moving, and the H5 makes changes to the selected function, steps, etc., at the moment this step loss occurs. It started happening with the X-axis, but now the Z-axis as well—it seems like the ESP is not capable of sending so many pulses.

The configuration is: X-axis 800 steps in the driver and 2400 in H5, and Z-axis 800 in the driver and 600 in H5.

I have changed the travel speed in SPEED_MANUAL_MOVE_Z = 8 * MOTOR_STEPS_Z. In the X-axis, I replaced the 8 with 3, and in the Z-axis, I changed the 8 to 5. It also does this in the movements that the H5 performs during automatic displacement without material loading or threading at 400 RPM and a pitch of 1.25mm.

What values should I adjust to prevent this? Is there any other speed adjustment? Errors continue to occur in the H5 when this happens because it changes values, functions...

By lowering the previous speed, it seems to happen much less, but at some point, it happens again.

On the other hand, when generating G-code, the X-axis movements make a loud noise similar to a step loss, but it doesn’t seem to actually lose steps.

Thank you very much for your help.

kachurovskiy, 2025-05-22:
This usually happens on brand-less cheap stepper drivers. Can you please post some pictures of your setup including wiring and all the components involved? Also your entire h5.ino via https://gist.github.com/. Thanks!

Jjjigu, 2025-05-22:
Hi, attach the pictures

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

this the stepper Z nema 34

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

driver Z ()this is good driver) (800 microsteps)

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

stepper X nema 17 1:3

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

driver X TB6600 (400 microsteps)

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

H5

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

With the configuration I've attached, all the H5's functions work well except for G-Code, which constantly loses steps only on the Z-axis. Could it be a problem with the TB6600?

kachurovskiy, 2025-05-23:
Yes, brand less cheap drivers like TB6600 give very rough movement and are likely to lose steps. Try a quality driver from e.g. Stepperonline or Rtelligent.

demsarmatjaz, 2025-05-23:
Hi, I would preffer closed loop steppers and appropriate drivers. As Maxim told, those drivers are not the best choice. The stepper itself is strong enough with 8,5Nm (if I am not wrong) but it must be driven with quality driver to get this torque from it. What voltage power supply did you take for Z axix driver? Maybe you could try with higher voltage, the driver can accept from 24VDC to 80VDC, I would go with at least 60VDC but rather 72VDC. Just my opinion...

Jjjigu, 2025-05-23:
The **Z-axis** is not giving me any problems with that driver, which is of good quality, and the power supply is **60 volts**. I only have issues if the speed increases significantly, but that doesn't worry me because I usually don't work at that speed.

The main problem is with the Z-axis, where I have a TB6600 driver with a 20-volt, 4-amp power supply, and the motor is 2 amps, and with this configirarion  only en gcode .

https://gist.github.com/Jjjigu/132e7efb54d0253a84019fc1700facf4

Do you recommend a specific driver? I was considering the **DM-556**.

Jjjigu, 2025-05-23:
Hi, i have test this configuration and the first test run ok in G code

const long SCREW_X_DU = 20000; // Husillo de bolas SFU1204 de 4 mm en deci-micrones (10^-7 de un metro)
const long MOTOR_STEPS_X = 2400;
const long SPEED_START_X = 400; // Velocidad inicial del motor, pasos / segundo.     MOTOR_STEPS_X
const long ACCELERATION_X = 4 * MOTOR_STEPS_X; // Aceleración del motor, pasos / segundo^2.
const long SPEED_MANUAL_MOVE_X = 3000; // Velocidad máxima del motor en movimiento manual, pasos / segundo.  2* MOTOR_STEPS_X
const bool INVERT_X = true; // Cambiar (true/false) si el carro se mueve p. ej. "a la izquierda" cuando presionas "derecha".
const bool NEEDS_REST_X = false; // Falso para cualquier tipo de driver o el eje X se desbloqueará cuando no esté en movimiento.
const long MAX_TRAVEL_MM_X = 100; // El carro transversal no permite viajar más de esto de una sola vez, 10 cm.
const long BACKLASH_DU_X = 0.05; // 0.15 mm de holgura en deci-micrones (10^-7 de un metro)
const char NAME_X = 'X'; // Texto mostrado en pantalla antes del valor de la posición del eje, nombre del eje en GCode.

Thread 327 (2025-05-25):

RMT to step generation.

RobinI30N, 2025-05-25:
What do you think.. would changing the step generation method to hardware RMT have any positive effects?

I am currently working on generating movement using this method.

kachurovskiy, 2025-05-25:
Sorry, not sure what RMT is and what problem are you looking to address.

RobinI30N, 2025-05-25:
I want to introduce a new quality :)
Generally speaking, RMT is a hardware square wave generator, it allows you to generate a series of pulses with a previously set timing for each pulse to control a stepper motor.
In this application, you can prepare the entire movement, including ramps. Unlike software pulse generation, it provides more precise movement.
The hardware handles the sending, relieving the load on the processor. Many CNC controllers use this method - for example (FluidNC).
If you want to continue developing the project, you should consider it, because you will eventually reach the end of the processor's computing capabilities.
When I have a demo ready, I can attach it for testing.

kachurovskiy, 2025-05-25:
It used to be a problem with Arduino but with ESP32 we are no longer constrained on pulse generation unless you go with very high micro-stepping.

Currently we know exactly how many pulses were issued and have 0 accumulating error. With hardware timers IIUC it's not possible to know how many pulses are issued exactly. The problem with accumulating error in timers is well demonstrated on YouTube with Chipmaker ELS.

Happy to be proven wrong and to see an improvement upon the existing work.

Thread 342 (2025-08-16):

Positional Error on Z axis

Festivejelly, 2025-08-16:
I've got a Z axis set up with these params:

const long SCREW_Z_DU = 50000; // 5mm lead screw in deci-microns (10^-7 of a meter)
const long MOTOR_STEPS_Z = 2000;
const long SPEED_START_Z = 2 * MOTOR_STEPS_Z; // Initial speed of a motor, steps / second.
const long ACCELERATION_Z = 20 * MOTOR_STEPS_Z; // Acceleration of a motor, steps / second ^ 2.
const long SPEED_MANUAL_MOVE_Z = 6 * MOTOR_STEPS_Z; // Maximum speed of a motor during manual move, steps / second.
const bool INVERT_Z = true; // change (true/false) if the carriage moves e.g. "left" when you press "right".
const bool NEEDS_REST_Z = false; // Set to false for closed-loop drivers, true for open-loop.
const long MAX_TRAVEL_MM_Z = 300; // Lathe bed doesn't allow to travel more than this in one go, 30cm / ~1 foot
const long BACKLASH_DU_Z = 200; // 400 = 0.04mm backlash in deci-microns (10^-7 of a meter)
const char NAME_Z = 'Z'; // Text shown on screen before axis position value, GCode axis name

I notice that when moving using the 1mm step the controller will often move short or too far by the backlash value.

For example if I zero Z and move left, then move right I end up with Z being 0.02mm short. So for example instead of the position being Z4 it ends up being Z3.98

This value changes based on the backlash amount set. So if I change the backlash to 400 du then the Z shows up as Z3.96

Any ideas what might be causing this? I put some logging in:

Move #1 - Before: z.pos=0, z.motorPos=0, z.originPos=0, z.pendingPos=0, z.fractionalPos=0.0000, moveStep=10000, direction=LEFT, z.backlashSteps=8
Move #1 - After: z.pos=4800, z.motorPos=4800, z.originPos=0, z.pendingPos=0, z.fractionalPos=0.0000, z.backlashSteps=8
Move #2 - Before: z.pos=4800, z.motorPos=4800, z.originPos=0, z.pendingPos=0, z.fractionalPos=0.0000, moveStep=10000, direction=RIGHT, z.backlashSteps=8
Move #2 - After: z.pos=1192, z.motorPos=1184, z.originPos=0, z.pendingPos=0, z.fractionalPos=0.0000, z.backlashSteps=8
Move #3 - Before: z.pos=1192, z.motorPos=1184, z.originPos=0, z.pendingPos=0, z.fractionalPos=0.0000, moveStep=10000, direction=RIGHT, z.backlashSteps=8
Move #3 - After: z.pos=-808, z.motorPos=-816, z.originPos=0, z.pendingPos=0, z.fractionalPos=0.0000, z.backlashSteps=8
Move #4 - Before: z.pos=-808, z.motorPos=-816, z.originPos=0, z.pendingPos=0, z.fractionalPos=0.0000, moveStep=10000, direction=RIGHT, z.backlashSteps=8
Move #4 - After: z.pos=-2008, z.motorPos=-2016, z.originPos=0, z.pendingPos=0, z.fractionalPos=0.0000, z.backlashSteps=8
Move #5 - Before: z.pos=-2008, z.motorPos=-2016, z.originPos=0, z.pendingPos=0, z.fractionalPos=0.0000, moveStep=10000, direction=LEFT, z.backlashSteps=8
Move #5 - After: z.pos=400, z.motorPos=400, z.originPos=0, z.pendingPos=0, z.fractionalPos=0.0000, z.backlashSteps=8

If I move via gcode I dont seem to get this positional error. Similarly if I change my Z axis pitch to 2mm instead of 5 then it also goes away.

This is on a H4 btw

Festivejelly, 2025-08-16:
With a 2mm pitch:

Move #1 - Before: z.pos=0, z.motorPos=0, z.originPos=0, z.pendingPos=0, z.fractionalPos=0.0000, moveStep=10000, direction=LEFT, z.backlashSteps=20
Move #1 - After: z.pos=9000, z.motorPos=9000, z.originPos=0, z.pendingPos=0, z.fractionalPos=0.0000, z.backlashSteps=20
Move #2 - Before: z.pos=9000, z.motorPos=9000, z.originPos=0, z.pendingPos=0, z.fractionalPos=0.0000, moveStep=10000, direction=RIGHT, z.backlashSteps=20
Move #2 - After: z.pos=-5000, z.motorPos=-5020, z.originPos=0, z.pendingPos=0, z.fractionalPos=0.0000, z.backlashSteps=20

I've tried to see where the differences are but my head is hurting now lol

kachurovskiy, 2025-08-17:
Both GCode and manual moves use `stepToContinuous()` so there should not be a difference in backlash logic since it's implemented inside - https://github.com/kachurovskiy/nanoels/blob/main/h4/h4.ino#L2617

Perhaps the error comes from the fact that on the initial move we assume the backlash is taken on the right side of the tool.

Festivejelly, 2025-08-19:
Weirdly adding DELAY(50); in the taskMoveZ seemed to fix it...

        z.speedMax = getStepMaxSpeed(&z);
        stepToContinuous(&z, posCopy + delta);
        waitForStep(&z);
        DELAY(50);
      } while (delta != 0 && (left ? buttonLeftPressed : buttonRightPressed));

Festivejelly, 2025-08-19:
Im not sure if that would be the cause, even if i wait like 10 seconds then do the change in direction it still appears. It seems to be tied to the pitch of the leadscrew and steps. My x axis is fine and doesnt exhibit this problem with a 2mm pitch.

But the 5mm pitch on z seems to cause issues.

I suspected it was because the task was being run over and over and not completing in time. Hence why i added a delay, and the delay seemed to fix it.

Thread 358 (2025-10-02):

Tachometer Issues (Can't Deal With High Speed)

GeckoSub, 2025-10-02:
So, before I do some drastic changes or start buying new hardware I wanted to ask here for ideas.

The tachometer on the H5 is fine up to around ~1600 rpm but if I increase the speed from there it's like the tacho gets overloaded and drops down to about 300rpm.
I am using a 600ppr encoder but it's geared 2:1 so it sees 1200ppr.
I think my spindle maxes out at around 2500rpm.

If this had been a real Omron it should easily be able to handle these numbers but maybe a cheap Chinese clone can't?
It's not an ESP32 limitation, right? Anything in the code that could explain this behaviour?

I may have a timing belt long enough to try a bigger pulley on the encoder so as to get to a 1:1 ratio and the "true" 600ppr of the encoder. Is that the smart, next move?

GeckoSub, 2025-10-03:
> Hey [@GeckoSub](https://github.com/GeckoSub), glad it worked out, sorry for not responding quickly, been doing a lot of driving lately.

No worries:)

When you have time, do you think this issue was an ESP limitation or just the encoder itself not being able to keep up?

kachurovskiy, 2025-10-03:
I'm not sure why would this happen, perhaps there's something in the code we need to tweak to adapt.

GeckoSub, 2025-10-04:
> I'm not sure why would this happen, perhaps there's something in the code we need to tweak to adapt.

Admittedly, I didn't try to replicate the issue on your stock FW... Let me try that in a day or two. Also, would be a good test to see if I got the RXTX splitter switch and USBTTL adapter set up correctly. The idea is that I flick a switch and move the USB-C cable to a second port on the panel for tft updates vs ESP reflashing. This, if it works, is a nice addition for people who tinker with the screenset and want to update it easily.

I'll report back:)

GeckoSub, 2025-10-06:
Turns out, the new USBTTL adapter I put in the panel doesn't work so can't reflash the Nextion. Not sure if it's a wiring issue or what, but won't have time to look into it for a while. Will keep this open and report back once I get around to it.

If the encoder high speed issue is present in the stock FW, it would make sense to get it looked at but don't want you to waste time until we have confirmed it:)

kachurovskiy, 2025-10-06:
During very high RPM there's probably not enough current to bring the encoder signal lines up to 5V and the signal becomes more and more flat until it stops triggering the PCNT. We don't use external pull up resistors on encoder lines and internal ones are very high resistance. Solution here would be to add e.g. two 2kOhm resistors from A and B encoder signal lines to 5V.

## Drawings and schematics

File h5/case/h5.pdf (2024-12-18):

## NanoEls H5

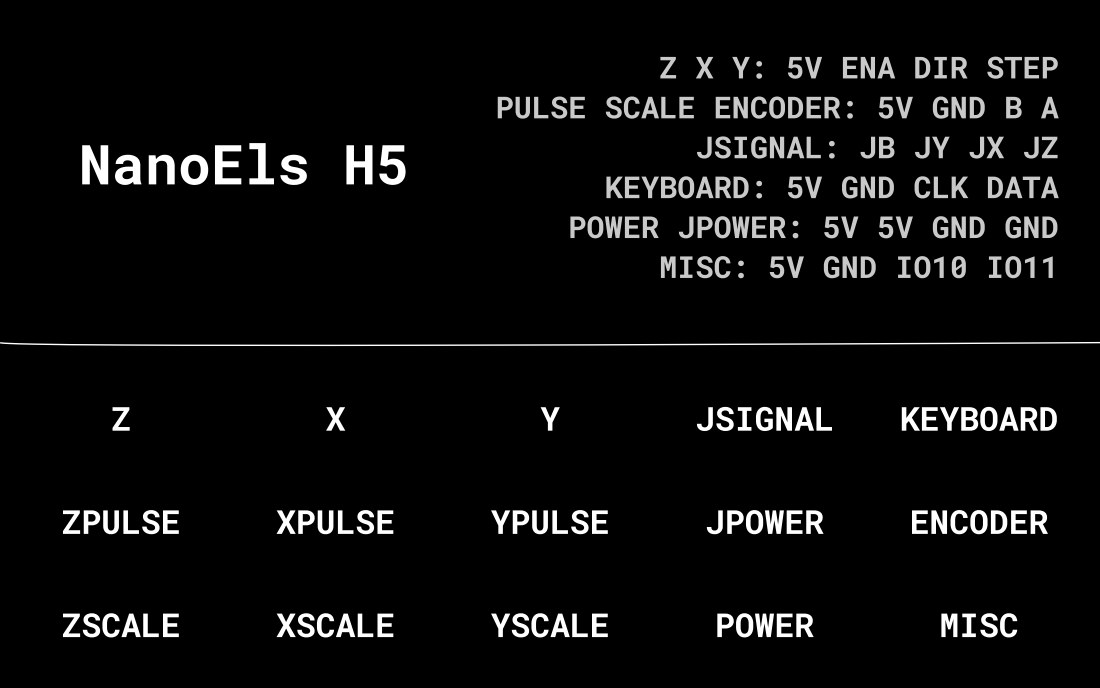
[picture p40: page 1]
JSIGNAL; KEYBOARD; ZPULSE; XPULSE; YPULSE; JPOWER; ENCODER; ZSCALE; XSCALE; YSCALE; POWER; MISC; MISC: 5V GND IO10 IO11

Z X Y: 5V ENA DIR STEP

PULSE SCALE ENCODER: 5V GND B A

JSIGNAL: JB JY JX JZ

KEYBOARD: 5V GND CLK DATA
POWER JPOWER: 5V 5V GND GND

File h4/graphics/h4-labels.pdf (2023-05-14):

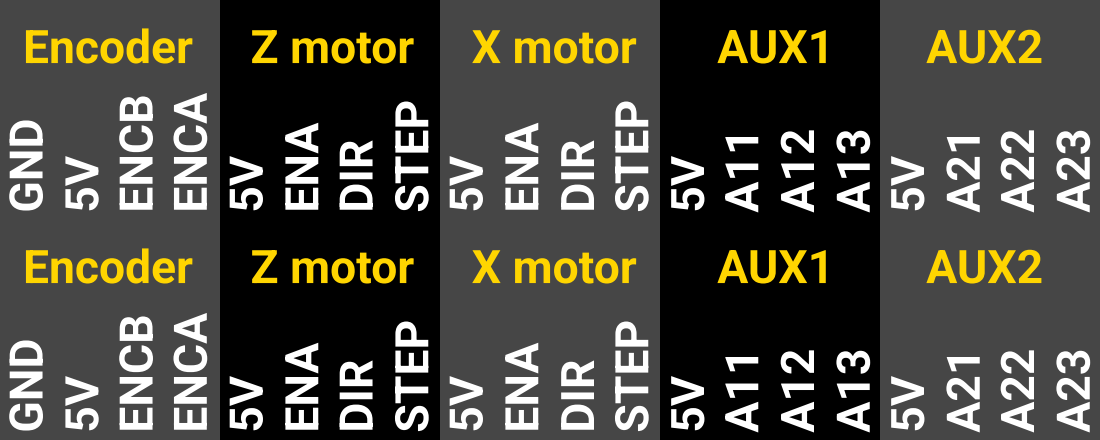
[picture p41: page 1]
GND; ENCB; ENCA; ENA; DIR; STEP; Encoder; Z motor; X motor; AUX1; AUX2

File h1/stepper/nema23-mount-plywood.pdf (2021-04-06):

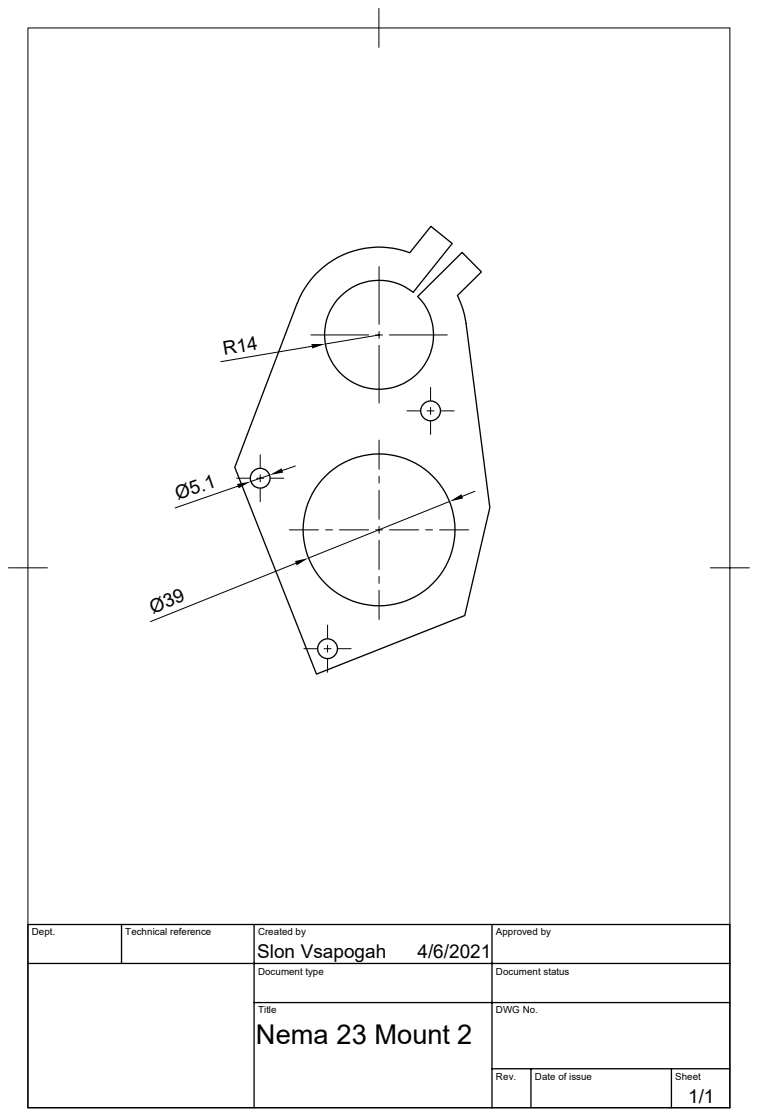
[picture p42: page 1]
Dept.; Technical reference; Created by; Approved by; Document type; Document status; Title; DWG No.; Rev.; Date of issue; Sheet; Nema 23 Mount 2; Slon Vsapogah

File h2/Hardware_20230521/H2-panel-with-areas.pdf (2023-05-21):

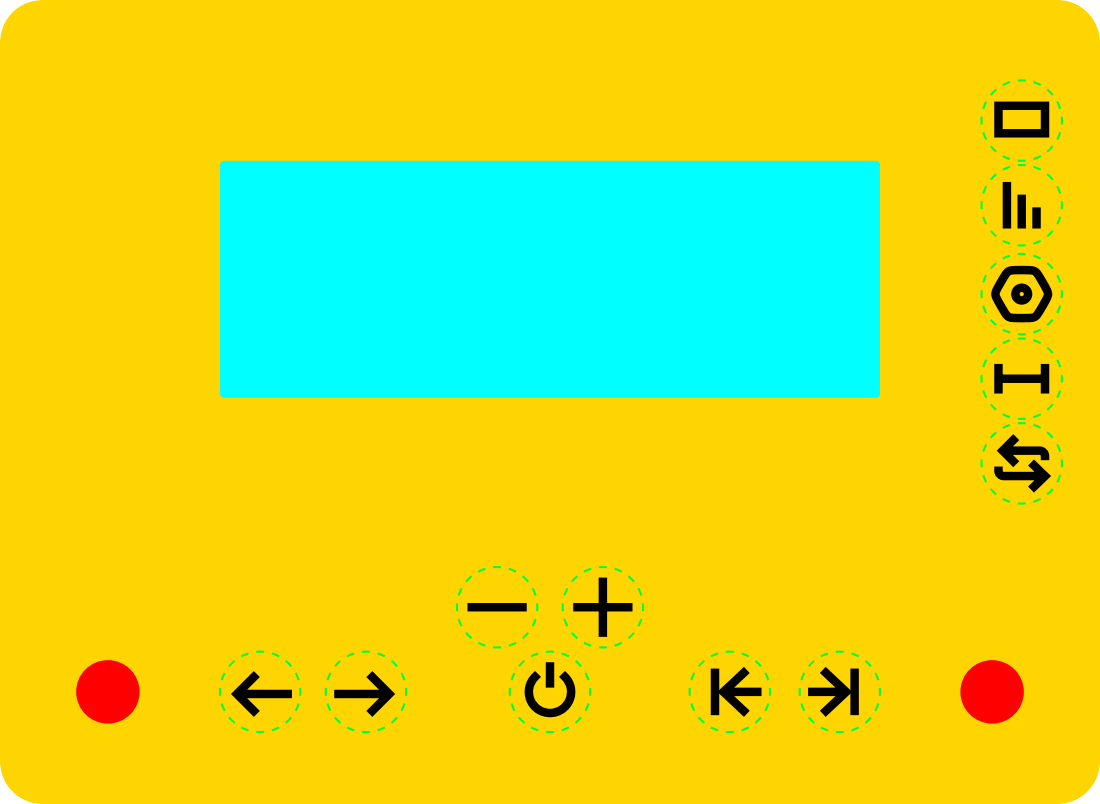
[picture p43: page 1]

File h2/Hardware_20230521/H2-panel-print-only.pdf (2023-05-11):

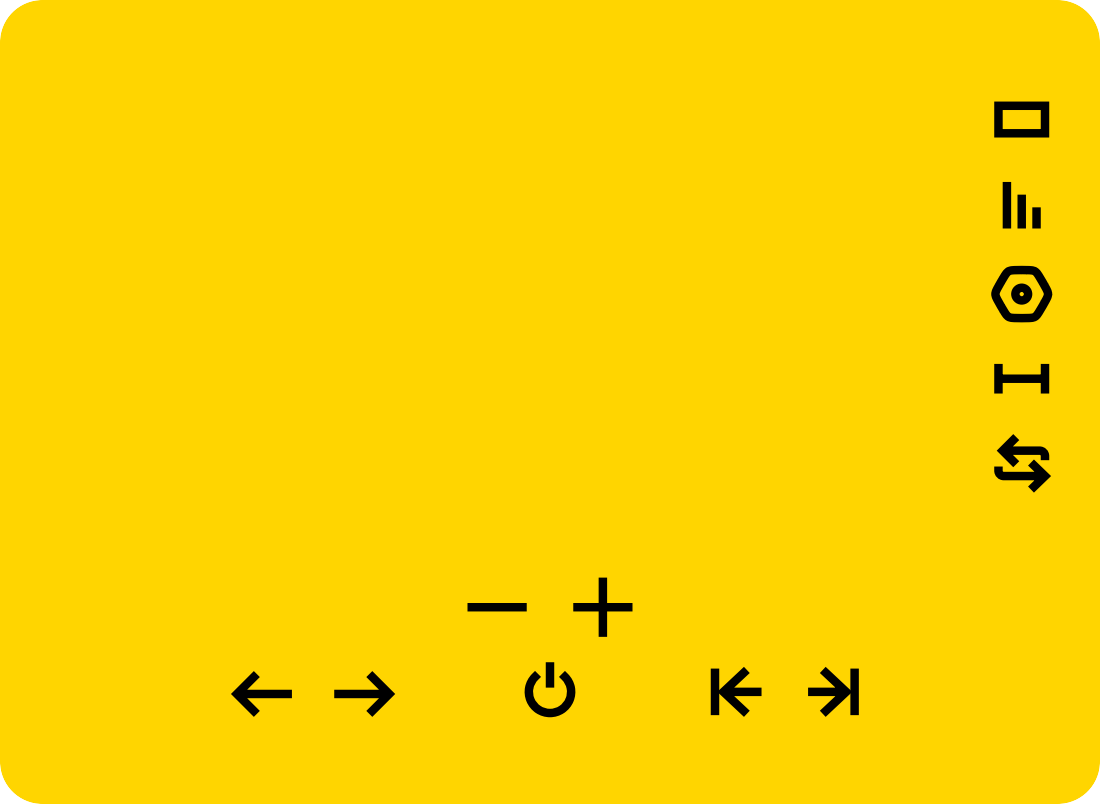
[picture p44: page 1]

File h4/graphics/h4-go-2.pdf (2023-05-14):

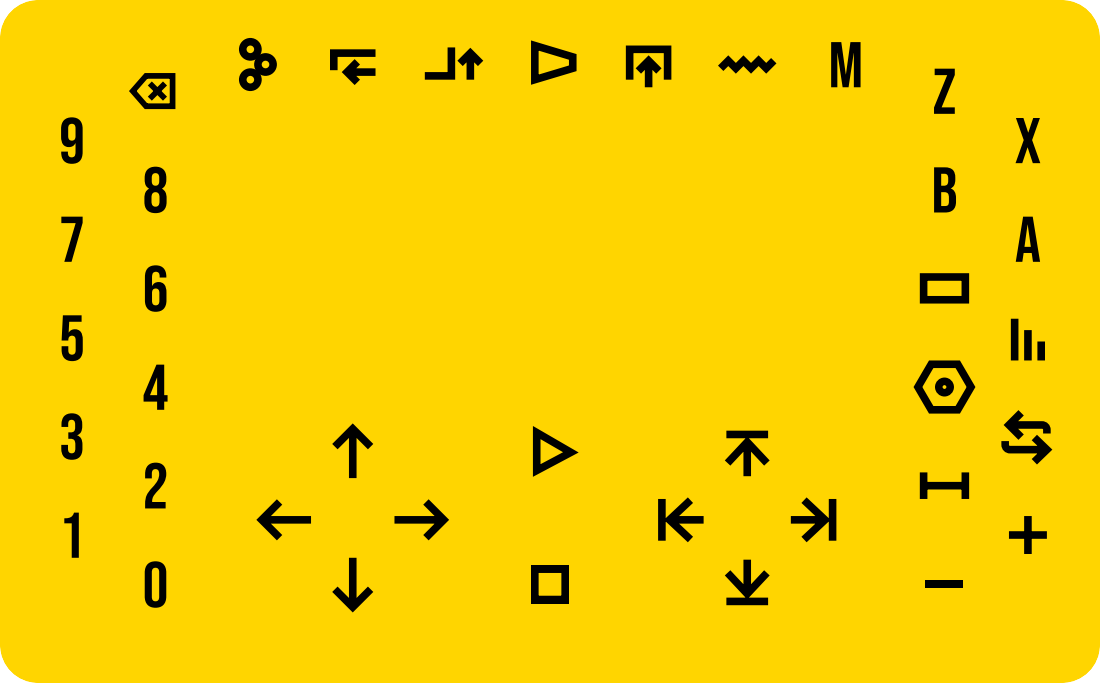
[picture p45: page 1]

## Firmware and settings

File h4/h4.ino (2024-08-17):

// https://github.com/kachurovskiy/nanoels

/* Change values in this section to suit your hardware. */

// Define your hardware parameters here.
const int ENCODER_PPR = 600; // 600 step spindle optical rotary encoder. Fractional values not supported.
const int ENCODER_BACKLASH = 3; // Numer of impulses encoder can issue without movement of the spindle

// Spindle rotary encoder pins. Swap values if the rotation direction is wrong.
#define ENC_A 7
#define ENC_B 15

// Main lead screw (Z) parameters.
const long SCREW_Z_DU = 20000; // 2mm lead screw in deci-microns (10^-7 of a meter)
const long MOTOR_STEPS_Z = 800;
const long SPEED_START_Z = 2 * MOTOR_STEPS_Z; // Initial speed of a motor, steps / second.
const long ACCELERATION_Z = 30 * MOTOR_STEPS_Z; // Acceleration of a motor, steps / second ^ 2.
const long SPEED_MANUAL_MOVE_Z = 6 * MOTOR_STEPS_Z; // Maximum speed of a motor during manual move, steps / second.
const bool INVERT_Z = false; // change (true/false) if the carriage moves e.g. "left" when you press "right".
const bool NEEDS_REST_Z = false; // Set to false for closed-loop drivers, true for open-loop.
const long MAX_TRAVEL_MM_Z = 300; // Lathe bed doesn't allow to travel more than this in one go, 30cm / ~1 foot
const long BACKLASH_DU_Z = 6500; // 0.65mm backlash in deci-microns (10^-7 of a meter)
const char NAME_Z = 'Z'; // Text shown on screen before axis position value, GCode axis name

// Cross-slide lead screw (X) parameters.
const long SCREW_X_DU = 12500; // 1.25mm lead screw with 3x reduction in deci-microns (10^-7) of a meter
const long MOTOR_STEPS_X = 2400; // 800 steps at 3x reduction
const long SPEED_START_X = MOTOR_STEPS_X; // Initial speed of a motor, steps / second.
const long ACCELERATION_X = 10 * MOTOR_STEPS_X; // Acceleration of a motor, steps / second ^ 2.
const long SPEED_MANUAL_MOVE_X = 3 * MOTOR_STEPS_X; // Maximum speed of a motor during manual move, steps / second.
const bool INVERT_X = true; // change (true/false) if the carriage moves e.g. "left" when you press "right".
const bool NEEDS_REST_X = false; // Set to false for all kinds of drivers or X will be unlocked when not moving.
const long MAX_TRAVEL_MM_X = 100; // Cross slide doesn't allow to travel more than this in one go, 10cm
const long BACKLASH_DU_X = 1500; // 0.15mm backlash in deci-microns (10^-7 of a meter)
const char NAME_X = 'X'; // Text shown on screen before axis position value, GCode axis name

// Manual stepping with left/right/up/down buttons. Only used when step isn't default continuous (1mm or 0.1").
const long STEP_TIME_MS = 500; // Time in milliseconds it should take to make 1 manual step.
const long DELAY_BETWEEN_STEPS_MS = 80; // Time in milliseconds to wait between steps.

/* Changing anything below shouldn't be needed for basic use. */

// Configuration for axis connected to A1. This is uncommon. Dividing head (C) motor parameters.
// Throughout the configuration below we assume 1mm = 1degree of rotation, so 1du = 0.0001degree.
const bool ACTIVE_A1 = false; // Whether the axis is connected
const bool ROTARY_A1 = true; // Whether the axis is rotary or linear
const long MOTOR_STEPS_A1 = 300; // Number of motor steps for 1 rotation of the the worm gear screw (full step with 20:30 reduction)
const long SCREW_A1_DU = 20000; // Degrees multiplied by 10000 that the spindle travels per 1 turn of the worm gear. 2 degrees.
const long SPEED_START_A1 = 1600; // Initial speed of a motor, steps / second.
const long ACCELERATION_A1 = 16000; // Acceleration of a motor, steps / second ^ 2.
const long SPEED_MANUAL_MOVE_A1 = 3200; // Maximum speed of a motor during manual move, steps / second.
const bool INVERT_A1 = false; // change (true/false) if the carriage moves e.g. "left" when you press "right".
const bool NEEDS_REST_A1 = false; // Set to false for closed-loop drivers. Open-loop: true if you need holding torque, false otherwise.
const long MAX_TRAVEL_MM_A1 = 360; // Probably doesn't make sense to ask the dividin head to travel multiple turns.
const long BACKLASH_DU_A1 = 0; // Assuming no backlash on the worm gear
const char NAME_A1 = 'C'; // Text shown on screen before axis position value, GCode axis name

// Manual handwheels on A1 and A2. Ignore if you don't have them installed.
const bool PULSE_1_USE = false; // Whether there's a pulse generator connected on A11-A13 to be used for movement.
const char PULSE_1_AXIS = NAME_Z; // Set to NAME_X to make A11-A13 pulse generator control X instead.
const bool PULSE_1_INVERT = false; // Set to true to change the direction in which encoder moves the axis
const bool PULSE_2_USE = false; // Whether there's a pulse generator connected on A21-A23 to be used for movement.
const char PULSE_2_AXIS = NAME_X; // Set to NAME_Z to make A21-A23 pulse generator control Z instead.
const bool PULSE_2_INVERT = true; // Set to false to change the direction in which encoder moves the axis
const float PULSE_PER_REVOLUTION = 100; // PPR of handwheels used on A1 and/or A2.
const long PULSE_MIN_WIDTH_US = 1000; // Microseconds width of the pulse that is required for it to be registered. Prevents noise.
const long PULSE_HALF_BACKLASH = 2; // Prevents spurious reverses when moving using a handwheel. Raise to 3 or 4 if they still happen.

const int ENCODER_STEPS_INT = ENCODER_PPR * 2; // Number of encoder impulses PCNT counts per revolution of the spindle
const int ENCODER_FILTER = 2; // Encoder pulses shorter than this will be ignored. Clock cycles, 1 - 1023.
const int PCNT_LIM = 31000; // Limit used in hardware pulse counter logic.
const int PCNT_CLEAR = 30000; // Limit where we reset hardware pulse counter value to avoid overflow. Less than PCNT_LIM.
const long DUPR_MAX = 254000; // No more than 1 inch pitch
const int32_t STARTS_MAX = 124; // No more than 124-start thread
const long PASSES_MAX = 999; // No more turn or face passes than this
const long SAFE_DISTANCE_DU = 5000; // Step back 0.5mm from the material when moving between cuts in automated modes
const long SAVE_DELAY_US = 5000000; // Wait 5s after last save and last change of saveable data before saving again
const long DIRECTION_SETUP_DELAY_US = 5; // Stepper driver needs some time to adjust to direction change
const long STEPPED_ENABLE_DELAY_MS = 100; // Delay after stepper is enabled and before issuing steps

// Version of the pref storage format, should be changed when non-backward-compatible
// changes are made to the storage logic, resulting in Preferences wipe on first start.
#define PREFERENCES_VERSION 1
#define PREF_NAMESPACE "h4"
#define GCODE_NAMESPACE "gc"

// GCode-related constants.
const float LINEAR_INTERPOLATION_PRECISION = 0.1; // 0 < x <= 1, smaller values make for quicker G0 and G1 moves
const long GCODE_WAIT_EPSILON_STEPS = 10;
const bool SPINDLE_PAUSES_GCODE = true; // pause GCode execution when spindle stops
const int GCODE_MIN_RPM = 30; // pause GCode execution if RPM is below this

// To be incremented whenever a measurable improvement is made.
#define SOFTWARE_VERSION 12

// To be changed whenever a different PCB / encoder / stepper / ... design is used.
#define HARDWARE_VERSION 4

#define Z_ENA 16
#define Z_DIR 17
#define Z_STEP 18

#define X_ENA 8
#define X_DIR 19
#define X_STEP 20

#define BUZZ 4
#define SCL 5
#define SDA 6

#define A11 9
#define A12 10
#define A13 11

#define A21 12
#define A22 13
#define A23 14

#define B_LEFT 57
#define B_RIGHT 37
#define B_UP 47
#define B_DOWN 67
#define B_MINUS 5
#define B_PLUS 64
#define B_ON 17
#define B_OFF 27
#define B_STOPL 7
#define B_STOPR 15
#define B_STOPU 6
#define B_STOPD 16
#define B_DISPL 14
#define B_STEP 24
#define B_SETTINGS 34
#define B_MEASURE 54
#define B_REVERSE 44
#define B_0 51
#define B_1 41
#define B_2 61
#define B_3 31
#define B_4 2
#define B_5 21
#define B_6 12
#define B_7 11
#define B_8 22
#define B_9 1
#define B_BACKSPACE 32
#define B_MODE_GEARS 42
#define B_MODE_TURN 52
#define B_MODE_FACE 62
#define B_MODE_CONE 3
#define B_MODE_CUT 13
#define B_MODE_THREAD 23
#define B_MODE_OTHER 33
#define B_X 53
#define B_Z 43
#define B_A 4
#define B_B 63

#define PREF_VERSION "v"
#define PREF_DUPR "d"
#define PREF_POS_Z "zp"
#define PREF_LEFT_STOP_Z "zls"
#define PREF_RIGHT_STOP_Z "zrs"
#define PREF_ORIGIN_POS_Z "zpo"
#define PREF_POS_GLOBAL_Z "zpg"
#define PREF_MOTOR_POS_Z "zpm"
#define PREF_DISABLED_Z "zd"
#define PREF_POS_X "xp"
#define PREF_LEFT_STOP_X "xls"
#define PREF_RIGHT_STOP_X "xrs"
#define PREF_ORIGIN_POS_X "xpo"
#define PREF_POS_GLOBAL_X "xpg"
#define PREF_MOTOR_POS_X "xpm"
#define PREF_DISABLED_X "xd"
#define PREF_POS_A1 "a1p"
#define PREF_LEFT_STOP_A1 "a1ls"
#define PREF_RIGHT_STOP_A1 "a1rs"
#define PREF_ORIGIN_POS_A1 "a1po"
#define PREF_POS_GLOBAL_A1 "a1pg"
#define PREF_MOTOR_POS_A1 "a1pm"
#define PREF_DISABLED_A1 "a1d"
#define PREF_SPINDLE_POS "sp"
#define PREF_SPINDLE_POS_AVG "spa"
#define PREF_OUT_OF_SYNC "oos"
#define PREF_SPINDLE_POS_GLOBAL "spg"
#define PREF_SHOW_ANGLE "ang"
#define PREF_SHOW_TACHO "rpm"
#define PREF_STARTS "sta"
#define PREF_MODE "mod"
#define PREF_MEASURE "mea"
#define PREF_CONE_RATIO "cr"
#define PREF_TURN_PASSES "tp"
#define PREF_MOVE_STEP "ms"
#define PREF_AUX_FORWARD "af"

#define MOVE_STEP_1 10000 // 1mm
#define MOVE_STEP_2 1000 // 0.1mm
#define MOVE_STEP_3 100 // 0.01mm

#define MOVE_STEP_IMP_1 25400 // 1/10"
#define MOVE_STEP_IMP_2 2540 // 1/100"
#define MOVE_STEP_IMP_3 254 // 1/1000" also known as 1 thou

#define MODE_NORMAL 0
#define MODE_ASYNC 2
#define MODE_CONE 3
#define MODE_TURN 4
#define MODE_FACE 5
#define MODE_CUT 6
#define MODE_THREAD 7
#define MODE_ELLIPSE 8
#define MODE_GCODE 9
#define MODE_A1 10

#define MEASURE_METRIC 0
#define MEASURE_INCH 1
#define MEASURE_TPI 2

#define ESTOP_NONE 0
#define ESTOP_KEY 1
#define ESTOP_POS 2
#define ESTOP_MARK_ORIGIN 3
#define ESTOP_ON_OFF 4
#define ESTOP_OFF_MANUAL_MOVE 5

// For MEASURE_TPI, round TPI to the nearest integer if it's within this range of it.
// E.g. 80.02tpi would be shown as 80tpi but 80.04tpi would be shown as-is.
const float TPI_ROUND_EPSILON = 0.03;

const float ENCODER_STEPS_FLOAT = ENCODER_STEPS_INT; // Convenience float version of ENCODER_STEPS_INT
const long RPM_BULK = ENCODER_STEPS_INT; // Measure RPM averaged over this number of encoder pulses
const long RPM_UPDATE_INTERVAL_MICROS = 1000000; // Don't redraw RPM more often than once per second

const long GCODE_FEED_DEFAULT_DU_SEC = 20000; // Default feed in du/sec in GCode mode
const float GCODE_FEED_MIN_DU_SEC = 167; // Minimum feed in du/sec in GCode mode - F1

#define DREAD(x) digitalRead(x)
#define DHIGH(x) digitalWrite(x, HIGH)
#define DLOW(x) digitalWrite(x, LOW)
#define DWRITE(x, y) digitalWrite(x, y)

#define DELAY(x) vTaskDelay(x / portTICK_PERIOD_MS);

// ESP32 hardware pulse counter library used to count spindle encoder pulses.
#include "driver/pcnt.h"

#include <SPI.h>
#include <Wire.h>
#include <LiquidCrystal.h>
LiquidCrystal lcd(21, 48, 47, 38, 39, 40, 41, 42, 2, 1);
#define LCD_HASH_INITIAL -3845709 // Random number that's unlikely to naturally occur as an actual hash
long lcdHashLine0 = LCD_HASH_INITIAL;
long lcdHashLine1 = LCD_HASH_INITIAL;
long lcdHashLine2 = LCD_HASH_INITIAL;
long lcdHashLine3 = LCD_HASH_INITIAL;
bool splashScreen = false;

#include <Preferences.h>

#include <Adafruit_TCA8418.h>
Adafruit_TCA8418 keypad;
unsigned long keypadTimeUs = 0;

// Most buttons we only have "down" handling, holding them has no effect.
// Buttons with special "holding" logic have flags below.
bool buttonLeftPressed = false;
bool buttonRightPressed = false;
bool buttonUpPressed = false;
bool buttonDownPressed = false;
bool buttonOffPressed = false;
bool buttonGearsPressed = false;
bool buttonTurnPressed = false;

bool inNumpad = false;
int numpadDigits[20];
int numpadIndex = 0;

bool isOn = false;
bool nextIsOn; // isOn value that should be applied asap
bool nextIsOnFlag; // whether nextIsOn requires attention
unsigned long resetMillis = 0;
int emergencyStop = 0;

bool beepFlag = false; // allows time-critical code to ask for a beep on another core

long dupr = 0; // pitch, tenth of a micron per rotation
long savedDupr = 0; // dupr saved in Preferences
long nextDupr = dupr; // dupr value that should be applied asap
bool nextDuprFlag = false; // whether nextDupr requires attention

SemaphoreHandle_t motionMutex; // controls blocks of code where variables affecting the motion loop() are changed

int starts = 1; // number of starts in a multi-start thread
int savedStarts = 0; // starts saved in Preferences
int nextStarts = starts; // number of starts that should be used asap
bool nextStartsFlag = false; // whether nextStarts requires attention

struct Axis {
  SemaphoreHandle_t mutex;

  char name;
  bool active;
  bool rotational;
  float motorSteps; // motor steps per revolution of the axis
  float screwPitch; // lead screw pitch in deci-microns (10^-7 of a meter)

  long pos; // relative position of the tool in stepper motor steps
  long savedPos; // value saved in Preferences
  float fractionalPos; // fractional distance in steps that we meant to travel but couldn't
  long originPos; // relative position of the stepper motor to origin, in steps
  long savedOriginPos; // originPos saved in Preferences
  long posGlobal; // global position of the motor in steps
  long savedPosGlobal; // posGlobal saved in Preferences
  int pendingPos; // steps of the stepper motor that we should make as soon as possible
  long motorPos; // position of the motor in stepper motor steps, same as pos unless moving back, then differs by backlashSteps
  long savedMotorPos; // motorPos saved in Preferences
  bool continuous; // whether current movement is expected to continue until an unknown position

  long leftStop; // left stop value of pos
  long savedLeftStop; // value saved in Preferences
  long nextLeftStop; // left stop value that should be applied asap
  bool nextLeftStopFlag; // whether nextLeftStop required attention

  long rightStop; // right stop value of pos
  long savedRightStop; // value saved in Preferences
  long nextRightStop; // right stop value that should be applied asap
  bool nextRightStopFlag; // whether nextRightStop requires attention

  long speed; // motor speed in steps / second
  long speedStart; // Initial speed of a motor, steps / second.
  long speedMax; // To limit max speed e.g. for manual moves
  long speedManualMove; // Maximum speed of a motor during manual move, steps / second.
  long acceleration; // Acceleration of a motor, steps / second ^ 2.
  long decelerateSteps; // Number of steps before the end position the deceleration should start.

  bool direction; // To reset speed when direction changes.
  bool directionInitialized;
  unsigned long stepStartUs;
  int stepperEnableCounter;
  bool disabled;
  bool savedDisabled;

  bool invertStepper; // change (true/false) if the carriage moves e.g. "left" when you press "right".
  bool needsRest; // set to false for closed-loop drivers, true for open-loop.
  bool movingManually; // whether stepper is being moved by left/right buttons
  long estopSteps; // amount of steps to exceed machine limits
  long backlashSteps; // amount of steps in reverse direction to re-engage the carriage
  long gcodeRelativePos; // absolute position in steps that relative GCode refers to

  int ena; // Enable pin of this motor
  int dir; // Direction pin of this motor
  int step; // Step pin of this motor
};

void initAxis(Axis* a, char name, bool active, bool rotational, float motorSteps, float screwPitch, long speedStart, long speedManualMove,
    long acceleration, bool invertStepper, bool needsRest, long maxTravelMm, long backlashDu, int ena, int dir, int step) {
  a->mutex = xSemaphoreCreateMutex();

  a->name = name;
  a->active = active;
  a->rotational = rotational;
  a->motorSteps = motorSteps;
  a->screwPitch = screwPitch;

  a->pos = 0;
  a->savedPos = 0;
  a->fractionalPos = 0.0;
  a->originPos = 0;
  a->savedOriginPos = 0;
  a->posGlobal = 0;
  a->savedPosGlobal = 0;
  a->pendingPos = 0;
  a->motorPos = 0;
  a->savedMotorPos = 0;
  a->continuous = false;

  a->leftStop = 0;
  a->savedLeftStop = 0;
  a->nextLeftStopFlag = false;

  a->rightStop = 0;
  a->savedRightStop = 0;
  a->nextRightStopFlag = false;

  a->speed = speedStart;
  a->speedStart = speedStart;
  a->speedMax = LONG_MAX;
  a->speedManualMove = speedManualMove;
  a->acceleration = acceleration;
  a->decelerateSteps = 0;
  long s = speedManualMove;
  while (s > speedStart) {
    a->decelerateSteps++;
    s -= a->acceleration / float(s);
  }

  a->direction = true;
  a->directionInitialized = false;
  a->stepStartUs = 0;
  a->stepperEnableCounter = 0;
  a->disabled = false;
  a->savedDisabled = false;

  a->invertStepper = invertStepper;
  a->needsRest = needsRest;
  a->movingManually = false;
  a->estopSteps = maxTravelMm * 10000 / a->screwPitch * a->motorSteps;
  a->backlashSteps = backlashDu * a->motorSteps / a->screwPitch;
  a->gcodeRelativePos = 0;

  a->ena = ena;
  a->dir = dir;
  a->step = step;
}

Axis z;
Axis x;
Axis a1;

unsigned long saveTime = 0; // micros() of the previous Prefs write
unsigned long spindleEncTime = 0; // micros() of the previous spindle update
unsigned long spindleEncTimeDiffBulk = 0; // micros() between RPM_BULK spindle updates
unsigned long spindleEncTimeAtIndex0 = 0; // micros() when spindleEncTimeIndex was 0
int spindleEncTimeIndex = 0; // counter going between 0 and RPM_BULK - 1
long spindlePos = 0; // Spindle position
long spindlePosAvg = 0; // Spindle position accounting for encoder backlash
long savedSpindlePosAvg = 0; // spindlePosAvg saved in Preferences
long savedSpindlePos = 0; // spindlePos value saved in Preferences
int spindleCount = 0; // Last processed spindle encoder pulse counter value.
int spindlePosSync = 0; // Non-zero if gearbox is on and a soft limit was removed while axis was on it
int savedSpindlePosSync = 0; // spindlePosSync saved in Preferences
long spindlePosGlobal = 0; // global spindle position that is unaffected by e.g. zeroing
long savedSpindlePosGlobal = 0; // spindlePosGlobal saved in Preferences

volatile int pulse1Delta = 0; // Outstanding pulses generated by pulse generator on terminal A1.
volatile int pulse2Delta = 0; // Outstanding pulses generated by pulse generator on terminal A2.

bool showAngle = false; // Whether to show 0-359 spindle angle on screen
bool showTacho = false; // Whether to show spindle RPM on screen
bool savedShowAngle = false; // showAngle value saved in Preferences
bool savedShowTacho = false; // showTacho value saved in Preferences
int shownRpm = 0;
unsigned long shownRpmTime = 0; // micros() when shownRpm was set

long moveStep = 0; // thousandth of a mm
long savedMoveStep = 0; // moveStep saved in Preferences

volatile int mode = -1; // mode of operation (ELS, multi-start ELS, asynchronous)
int nextMode = 0; // mode value that should be applied asap
bool nextModeFlag = false; // whether nextMode needs attention
int savedMode = -1; // mode saved in Preferences

int measure = MEASURE_METRIC; // Whether to show distances in inches
int savedMeasure = MEASURE_METRIC; // measure value saved in Preferences

float coneRatio = 1; // In cone mode, how much X moves for 1 step of Z
float savedConeRatio = 0; // value of coneRatio saved in Preferences
float nextConeRatio = 0; // coneRatio that should be applied asap
bool nextConeRatioFlag = false; // whether nextConeRatio requires attention

int turnPasses = 3; // In turn mode, how many turn passes to make
int savedTurnPasses = 0; // value of turnPasses saved in Preferences

long setupIndex = 0; // Index of automation setup step
bool auxForward = true; // True for external, false for external thread
bool savedAuxForward = false; // value of auxForward saved in Preferences

long opIndex = 0; // Index of an automation operation
bool opIndexAdvanceFlag = false; // Whether user requested to move to the next pass
long opSubIndex = 0; // Sub-index of an automation operation
int opDuprSign = 1; // 1 if dupr was positive when operation started, -1 if negative
long opDupr = 0; // dupr that the multi-pass operation started with

const int customCharMmCode = 0;
byte customCharMm[] = {
  B11010,
  B10101,
  B10101,
  B00000,
  B11010,
  B10101,
  B10101,
  B00000
};
const int customCharLimUpCode = 1;
byte customCharLimUp[] = {
  B11111,
  B00100,
  B01110,
  B10101,
  B00100,
  B00100,
  B00000,
  B00000
};
const int customCharLimDownCode = 2;
byte customCharLimDown[] = {
  B00000,
  B00100,
  B00100,
  B10101,
  B01110,
  B00100,
  B11111,
  B00000
};
const int customCharLimLeftCode = 3;
byte customCharLimLeft[] = {
  B10000,
  B10010,
  B10100,
  B11111,
  B10100,
  B10010,
  B10000,
  B00000
};
const int customCharLimRightCode = 4;
byte customCharLimRight[] = {
  B00001,
  B01001,
  B00101,
  B11111,
  B00101,
  B01001,
  B00001,
  B00000
};
const int customCharLimUpDownCode = 5;
byte customCharLimUpDown[] = {
  B11111,
  B00100,
  B01110,
  B00000,
  B01110,
  B00100,
  B11111,
  B00000
};
const int customCharLimLeftRightCode = 6;
byte customCharLimLeftRight[] = {
  B00000,
  B10001,
  B10001,
  B11111,
  B10001,
  B10001,
  B00000,
  B00000
};
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
void loop() {
  if (emergencyStop != ESTOP_NONE) {
    return;
  }
  if (xSemaphoreTake(motionMutex, 1) != pdTRUE) {
    return;
  }
  applySettings();
  processSpindleCounter();
  discountFullSpindleTurns();
  if (!isOn || dupr == 0 || spindlePosSync != 0) {
    // None of the modes work.
  } else if (mode == MODE_NORMAL) {
    modeGearbox();
  } else if (mode == MODE_TURN) {
    modeTurn(&z, &x);
  } else if (mode == MODE_FACE) {
    modeTurn(&x, &z);
  } else if (mode == MODE_CUT) {
    modeCut();
  } else if (mode == MODE_CONE) {
    modeCone();
  } else if (mode == MODE_THREAD) {
    modeTurn(&z, &x);
  } else if (mode == MODE_ELLIPSE) {
    modeEllipse(&z, &x);
  }
  moveAxis(&z);
  moveAxis(&x);
  if (ACTIVE_A1) moveAxis(&a1);
  xSemaphoreGive(motionMutex);
}

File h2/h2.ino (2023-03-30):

// https://github.com/kachurovskiy/nanoels

/* Change values in this section to suit your hardware. */

// Define your hardware parameters here. Don't remove the ".0" at the end.
#define ENCODER_STEPS 600.0 // 600 step spindle optical rotary encoder
#define MOTOR_STEPS 200.0
#define LEAD_SCREW_DU 20000.0 // 2mm lead screw in deci-microns (10^-7) of a meter

// Spindle rotary encoder pins. Nano only supports interrupts on D2 and D3.
// Swap values if the rotation direction is wrong.
#define ENC_A 3 // D3
#define ENC_B 2 // D2

// Stepper pulse and acceleration constants.
#define PULSE_MIN_US round(500.0 * 200.0 / MOTOR_STEPS) // Microseconds to wait after high pulse, min.
#define PULSE_MAX_US round(2000.0 * 200.0 / MOTOR_STEPS) // Microseconds to wait after high pulse, max. Slow start.
#define ACCELERATION 20
#define INVERT_STEPPER false // change (true/false) if the carriage moves e.g. "left" when you press "right".
#define DISABLE_STEPPER_WHEN_RESTING false

// Voltage on A6 when F1-F5 buttons are pressed.
// If those buttons don't work as expected, uncomment "// Serial.println(value);" in getAnalogButton(),
// upload sketch to your Arduino and click each button (topmost is F1) to find the right value for each.
// If values are too close to each other (should be ~170 apart), improve resistor soldering connections.
#define F1_VOLTAGE 850
#define F2_VOLTAGE 679
#define F3_VOLTAGE 509
#define F4_VOLTAGE 339
#define F5_VOLTAGE 169

/* Changing anything below shouldn't be needed for basic use. */

// Analog voltage epsilon allowing for slightly imprecise resistances.
// Should be around (F1_VOLTAGE - F2_VOLTAGE) / 3
#define BUTTON_EPSILON 50

#define LONG_MIN long(-2147483648)
#define LONG_MAX long(2147483647)

#define LOOP_COUNTER_MAX 1500 // 1500 loops without stepper move to start reading buttons
#define DUPR_MAX 100000 // 10mm
#define STARTS_MAX 124 // No more than 124-start thread

// Ratios between spindle and stepper.
#define ENCODER_TO_STEPPER_STEP_RATIO MOTOR_STEPS / (LEAD_SCREW_DU * ENCODER_STEPS)
#define STEPPER_TO_ENCODER_STEP_RATIO LEAD_SCREW_DU * ENCODER_STEPS / MOTOR_STEPS

// If time between encoder ticks is less than this, direction change is not allowed.
// Effectively this limits direction change to the time when spindle is <20rpm.
#define DIR_CHANGE_DIFF_MICROS (int) (5000 * ENCODER_STEPS / 600)

// Version of the EEPROM storage format, should be changed when non-backward-compatible
// changes are made to the storage logic, resulting in EEPROM wipe on first start.
#define EEPROM_VERSION 3

// To be incremented whenever a measurable improvement is made.
#define SOFTWARE_VERSION 7

// To be changed whenever a different PCB / encoder / stepper / ... design is used.
#define HARDWARE_VERSION 2

#define DIR 11
#define STEP 12
#define ENA 13

#define B_LEFT  4
#define B_RIGHT 5
#define B_MINUS 6
#define B_PLUS  7
#define B_ONOFF 8
#define B_STOPL 9
#define B_STOPR 10
#define B_F1 11
#define B_F2 12
#define B_F3 13
#define B_F4 14
#define B_F5 15

#define ADDR_EEPROM_VERSION 0 // takes 1 byte
#define ADDR_DUPR 2 // takes 4 bytes
#define ADDR_POS 6 // takes 4 bytes
#define ADDR_LEFT_STOP 10 // takes 4 bytes
#define ADDR_RIGHT_STOP 14 // takes 4 bytes
#define ADDR_SPINDLE_POS 18 // takes 4 bytes
#define ADDR_OUT_OF_SYNC 22 // takes 2 bytes
#define ADDR_SHOW_ANGLE 24 // takes 1 byte
#define ADDR_SHOW_TACHO 25 // takes 1 byte
#define ADDR_MOVE_STEP 26 // takes 2 bytes
#define ADDR_STARTS 28 // takes 2 bytes
#define ADDR_MODE 30 // takes 2 bytes
#define ADDR_MEASURE 32 // takes 2 bytes

#define MOVE_STEP_1 10000 // 1mm
#define MOVE_STEP_2 1000 // 0.1mm
#define MOVE_STEP_3 100 // 0.01mm
#define MOVE_STEP_4 10 // 1 micron
#define MOVE_STEP_IMP_1 25400 // 1/10"
#define MOVE_STEP_IMP_2 2540 // 1/100"
#define MOVE_STEP_IMP_3 254 // 1/1000" also known as 1 thou

#define MODE_NORMAL 0
#define MODE_MULTISTART 1
#define MODE_ASYNC 2

#define MEASURE_METRIC 0
#define MEASURE_INCH 1
#define MEASURE_TPI 2

// For MEASURE_TPI, round TPI to the nearest integer if it's within this range of it.
// E.g. 80.02tpi would be shown as 80tpi but 80.04tpi would be shown as-is.
#define TPI_ROUND_EPSILON 0.03

#define RPM_BULK ENCODER_STEPS // Measure RPM averaged over this number of encoder pulses
#define RPM_UPDATE_INTERVAL_MICROS 1000000 // Don't redraw RPM more often than once per second

// Uncomment to print out debug info in Serial.
// #define DEBUG

// Uncomment to run the self-test of the code instead of the actual program.
// #define TEST
#ifdef TEST
bool mockDigitalPins[20] = {0};
int mockDigitalPinToggleOnRead = -1;
int mockDigitalRead(int x) {
  int value = mockDigitalPins[x];
  if (x == mockDigitalPinToggleOnRead) {
    mockDigitalPins[x] ^= 1;
  }
  return value;
}
int mockDigitalWrite(int x, int value) {
  mockDigitalPins[x] = value;
}
#define DREAD(x) mockDigitalRead(x)
#define DHIGH(x) mockDigitalWrite(x, HIGH)
#define DLOW(x) mockDigitalWrite(x, LOW)
#else
#include <FastGPIO.h>
#define DREAD(x) FastGPIO::Pin<x>::isInputHigh()
#define DHIGH(x) FastGPIO::Pin<x>::setOutputHigh()
#define DLOW(x) FastGPIO::Pin<x>::setOutputLow()
#endif

#ifndef TEST
#include <SPI.h>
#include <Wire.h>
#include <LiquidCrystal.h>
LiquidCrystal lcd(A0, A1, A2, A3, A4, A5);
long lcdHash = 0;
#endif

#include <EEPROM.h>

unsigned long buttonDownTime = 0;
unsigned long buttonUpTime = 0;
int buttonId = 0;
volatile long loopCounter = 0;
int buttonLoopCounter = 0;
bool isOn = false;
unsigned long resetMillis = 0;
bool resetOnStartup = false;
bool emergencyStop = false;

volatile long dupr = 0; // pitch, tenth of a micron per rotation
long savedDupr = 0; // dupr saved in EEPROM
long duprPrevious = 0;

int starts = 1; // number of starts in a multi-start thread
int savedStarts = 0; // starts saved in EEPROM

volatile long pos = 0; // relative position of the stepper motor, in steps
long savedPos = 0; // value saved in EEPROM
float fractionalPos = 0.0; // fractional distance in steps that we meant to travel but couldn't

volatile long leftStop = 0; // left stop value of pos
long savedLeftStop = 0; // value saved in EEPROM
bool leftStopFlag = true; // prevent toggling the stop while button is pressed.

volatile long rightStop = 0; // right stop value of pos
long savedRightStop = 0; // value saved in EEPROM
bool rightStopFlag = true; // prevent toggling the stop while button is pressed.
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

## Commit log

2020-11-27 NanoEls hardware version 1, software version 1, pcb revision 1
    [case-120mm-2m6-2m5-4m3.stl, encoder-base-38.5mm-hole-m4-screw.stl, encoder-gear-60t-6.1mm-bore.stl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]
2020-11-28 Add an assembly image
2020-11-30 Version 2: fixes and improvements
    [NanoEls.ino]
2020-11-30 Fix PCB button label and use date for versioning
2020-12-01 Lower stepper min/max speeds to reduce noise and chances of skipped steps
    [NanoEls.ino]
2020-12-06 Fixing the soft-start issue
    [NanoEls.ino]
2020-12-07 Possible fix for the stepper direction bug
    [NanoEls.ino]
2020-12-09 Add new files
    [stepper-to-gear-adapter-12mm-10mm.stl]
2020-12-12 Support belt connection between the stepper and the leadscrew
2020-12-12 16 tooth pulleys for the belt connection
    [htd5m-16t-10b.stl, htd5m-16t-12b.stl]
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2020-12-20 Optimizations and bug fixes, unit tests
    [NanoEls.ino, Tests.ino]
2020-12-21 Fixing the faulty spindle sync logic, unit tests
    [NanoEls.ino, Tests.ino]
2020-12-24 Adding more unit tests, fixing stepper reverses
    [NanoEls.ino, Tests.ino]
2020-12-25 New PCB version candidate
2020-12-25 Fixing a bunch of negative hmmpr and other bugs, support movement onto the stop, more tests
    [NanoEls.ino, Tests.ino]
2020-12-27 Software Version 6: show linear position and spindle angle
2020-12-28 Don't show spindle angle by default, allow jogging with turning spindle if off, make the ruler work when off
2020-12-29 Speed up button reads, support off/+/- when ELS is ON, fix stepper timings for microstepping
    [NanoEls.ino, Tests.ino]
2020-12-29 Don't show LTW on startup if ELS is off. Thread will be lost anyway when it's turned on.
2020-12-31 New PCB confirmed working
2021-01-02 Fix off-by-one errors when working with left and right stops
    [NanoEls.ino, Tests.ino]
2021-01-02 Fix moving left/right when isOn and hmmpr is 0 or 1
    [NanoEls.ino, Tests.ino]
2021-01-04 Toggle spindle angle indicator by pressing - and + at the same time
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2021-04-06 Add stepper mount PDF
2021-04-07 8mm bore pulley
    [htd5m-16t-8b.stl]
2021-07-03 Standalone box image and STL
    [nanoels-box-part1.stl, nanoels-box-part2.stl]
2021-07-03 Resizing the case image
2021-07-03 Adjusting the case image
2021-07-12 Fix case part 2 STL URL
2021-07-27 Encoder Fusion models
    [encoder-base-38.5mm-hole-m4-screw.f3d]
2021-10-13 Adding a 60t gear suitable for encoders ~59mm tall
    [encoder-gear-60t-6.1mm-bore-for-encoder-59mm-tall.stl]
2021-10-14 Try to make the 60t encoder gear fit on the lathe
    [encoder-gear-60t-6.1mm-bore-for-encoder-59mm-tall.stl]
2021-12-05 Linking new models for encoder base and stepper mount
    https://github.com/kachurovskiy/nanoels/issues/18
2021-12-14 Stepper mount Fusion file
    [stepper-mount-nema23-28mm-hole.f3d]
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2021-12-16 Update wiring image with the new PCB version
2021-12-20 Adding Fusion 360 model for the HTD 5M pulleys
    [htd5m.f3d]
2022-02-27 Case Fusion model
    [nanoels-box.f3d]
2022-09-02 Initial version of NanoElsLcd, work in progress
    [nanoels-lcd-button.stl, nanoels-lcd-case.stl, nanoels-lcd-lid.stl]
2022-09-03 Fix the stepper enabling logic
    [h2.ino]
2022-09-04 Fix stepper ENA logic
    [h2.ino]
2022-09-04 Support moving the spindle using LEFT/RIGHT while ON and in motion
2022-09-26 Model updates
    [nanoels-lcd-button.stl, nanoels-lcd-case.stl, nanoels-lcd-lid.stl]
2022-10-22 Support 0.001mm pitch increments. Use double digit angle precision.
2022-10-23 Fix RPM calculation and display
    [h2.ino]
2022-10-23 Only update displayed angle once the spindle stopped
2022-10-24 Dramatically improve stepper acceleration, check all buttons when ON, improve display freshness
2022-11-02 Multi-start logic via button F3
2022-11-02 Documentation for multi-start threads
2022-11-23 Servos don't need to be disabled when resting, in fact they have problems doing so requring delays on when enabled, allow for that
    [h2.ino]
2022-12-17 Support async mode, change how multi-start thread is setup
2022-12-17 Fix starting ELS when spindle is moving and movement with negative pitch in ASYNC mode
    [h2.ino]
2023-01-02 Don't show trailing precision points if they are 0. Don't show 'mm' after 0 since 0mm = 0m = 0inch.
2023-01-10 Protect buttons against noise. Fix fraction problems incrementing pitch by 0.01 and 0.001 inches. Throw away unwanted precision points when modifying pitch.
    [h2.ino]
2023-01-10 Correctly initialize direction if ELS is turned on while spindle is running
    [h2.ino]
2023-01-23 Fix a crash that happened when running in async mode with negative pitch for some time
    [h2.ino]
2023-03-25 Stop everything if a button is pressed on power-on, assume hardware failure
    [h2.ino]
2023-03-25 Don't filter OFF button presses for noise and time conditions
    [h2.ino]
2023-03-30 Fixed unit tests, stop buttons holding logic
    [Tests.ino, h2.ino]
2023-04-18 Remove unused "resetOnStartup" in h2. Initial version of h4.
    [Tests.ino, h4.ino]
2023-04-23 Update display on another core. Hash and print each line independently.
2023-04-25 Fix updateDisplay() and button pins
    [h4.ino]
2023-04-25 Fix encoder direction bug, decouple pos from displayed position
    [h4.ino]
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2023-04-30 Support for X axis, cone mode, work in progress
2023-05-02 Fix cone mode problem with limits, jumps on dupr change
    [h4.ino]
2023-05-04 Manual motor disable, emergency stop, cone fixes
    [h4.ino]
2023-05-04 Speed up estop determination, more thread safety
2023-05-05 Fix cone limits for negative pitch
    [h4.ino]
2023-05-05 Fix rare jumping when turning cone off, use common cone ratio definition as (D-d)/L, 45deg = cone ratio 2
    [h4.ino]
2023-05-06 Stay in the thread in MODE_TURN
2023-05-07 Fix lost encoder pulses due to EEPROM.commit()
    [h4.ino]
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2023-05-08 Fix cone mode startup
    [h4.ino]
2023-05-08 Fix crash when leaving SYN, move encoder pulse processing logic out of the interrupt
    [h4.ino]
2023-05-09 Initial version of the thread mode
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2023-05-11 External/internal variation for turn, face, thread and cut
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2023-05-13 Stay in the thread between runs in MODE_TURN, _FACE and _THREAD
2023-05-13 Fix an intermittent problem with cone rushing from stop
    [h4.ino]
2023-05-13 Replace MUL mode with multi-start support in THRD
    [h4.ino]
2023-05-13 Show correct number of operations for multistart
    [h4.ino]
2023-05-14 PCB design, 3D models and printed source files
    [BOM_PCB_H4Keypad_2023-05-01.csv, BOM_PCB_H4_2023-05-01.csv, NanoElsH4-3dp-Back.stl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]
2023-05-16 Backlash compensation at low level, fix reset screen update, fix unexpected motor speed drop, fix setting limits while moving
    [h4.ino]
2023-05-20 Step back a safe distance from the part on the way back when threading/turning/facing
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2023-05-21 Document backlash compensation in "Moving"
2023-05-21 Fix micros overflow bugs - H4 not moving axes and not saving prefs after some time
    [h4.ino]
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2023-05-21 Sharing latest hardware design for H2
    [BOM_PCB_NanoElsLcdSmdFull_2023-04-04.csv, NanoElsH2-Back.stl, NanoElsH2-Case.stl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]
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2023-05-22 Fix gearbox thread loss, speed up motion loop
    [h4.ino]
2023-05-22 Encoder backlash to prevent short reverses at high spindle speed
    [h4.ino]
2023-05-25 Move with pulse generators. GRBL & gcode sender.
2023-05-26 Fix pitch changes while running turn/face/thread
    [h4.ino]
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2023-06-14 Delay after dir change. Remove 1u step. Custom chars. Fix cone unexpected move. Fix async dir after move. Fix potential race in setIsOn. Fix X precise move. Potentially fix move stall.
    [h4.ino]
2023-06-15 Fix reset splash screen
    [h4.ino]
2023-06-15 Fix running GCode via sender.html
    [h4.ino]
2023-06-15 Fix GCode relative positioning
    [h4.ino]
2023-06-17 Support zeroing Z or X at a given distance ahead of current position
2023-06-17 Workaround for the motor stall bug
    [h4.ino]
2023-06-19 Improve back lid 3D model
    [NanoElsH4-3dp-Back.stl]
2023-06-19 Add a shim to be used between keypad and display to support keypad top row of buttons
    [KeypadShim5x30x2.4-Body.stl]
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2023-06-22 V5. Support for A1 axis. Persist stepper disable. Persist external/internal. Don't save to flash within 5s of keypad event. Handle mode and on/off changes on main thread to avoid reboots. Deceleratio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
    [h4.ino]
2023-07-23 H4 version 6, fixes and improvements.
    Using const instead of define for configuration values to avoid define pitfalls.
    Increase default X manual move speed.
    Decrease default Z acceleration.
    Limit GCode minumum speed 1mm/min.
    Show distance between limits when starting the operation.
    Show distance to start point when starting the operation.
    Fix "1 passes" line.
    Fix repeated enabling/disabling on A1 during manual move.
    Fix displaying of the "key pressed on start" emergency stop state.
    Entering diameter and pressing A sets X0 as -diameter/2.
    Implement "Internal" ellipses as having same start/end points as "External" but concave.
    Fix problem with stuck CUT when left limit is set on current Z.
    [h4.ino]
2023-11-02 Fix for the wrong free move speed during tuning/facing/auto-threading
    [h4.ino]
2023-11-05 Add a note on low voltage/current for 5V lines
2023-11-11 Link to a cheaper encoder that also tolerates lower voltage
2023-12-19 Fix setting X0 from diameter when position is not 0. Version 8.
    [h4.ino]
2023-12-21 Fix bug in async mode position when moving left. Version 8.
    [h4.ino]
2023-12-21 Fix bug in async mode position when moving left. Version 9.
    [h4.ino]
2023-12-23 Update hardware docs
    [EncoderMount38.4mm-Body.step, EncoderMount38.4mm-Wheel.step, EncoderMount38.4mm.FCStd]
2023-12-23 Correct STL to STEP in the docs
2024-01-21 Version 11: stored GCode programs, pause GCode when spindle stops
2024-02-13 Version 12: hardware pulse counter for spindle encoder
2024-08-17 espressif_3.0 (#210)
    Fix compilation errors for the latest Arduino version
    [h4.ino]
2024-11-10 H5 PCB and case
    [h5-CaseMid.step, h5-CaseTop.step, h5.FCStd]
2024-12-18 H5 initial version
    [esp32devkit.FCStd, h5-CaseMid.step, h5-CaseTop.step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]
2024-12-18 Move terminal labels from the 3D print to a normal print
2024-12-29 H5: fix RPM, show number of turns, fix printing mode, using PS2KeyAdvanced lib, support more PS2 keyboard types
2025-01-12 Fix Y axis initialization
2025-01-13 V3. Using ENCODER_FILTER 1 as that helped a user with lost pulses. Comments for key codes. O as diameter button #250. Q as Z-enable button #248. Increase splash screen time by 300ms #247. All modes h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
2025-01-14 H5 mounting arm
    [h5.FCStd, h5handle.step, h5mount1.step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]
2025-06-22 V9: cone threading, invert enable, prevent X display jumps
2025-08-23 H5V11: touch screen support, y mode fixes, multistart button
2025-11-05 Minor corrections in the h5 README
    Clarified instructions for spindle direction and WiFi setup.
2025-11-16 Show diameter, fix wheel movement when gear on, turn off wheels in pass modes, reduce X travel in turn and face, differential thread passes
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2025-11-22 H5V13: fix conical threads, improve screen responsiveness
2026-02-22 Workaround for deadline when installing esp32
2026-02-25 Model for 3D printed SD card handle - easy insertion and removal
    [h5.FCStd, h5sdhandle.step]
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2026-05-06 Allow going down to starts=1 when setting up threading using a minus button #368
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2026-05-09 Reverse keeps you in the thread
2026-05-09 Improve JOY mode feed clutch and threading phase sync
2026-05-09 Joystick Y now adjusts pitch outside JOY too
2026-05-09 Fix status line flickering when adjusting pitch.
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2026-05-16 Optional: joystick button as ON/OFF in JOY mode
2026-05-16 Work-in-progress joystick PCB and case
    [Joystick-CaseBottom.step, Joystick-CaseTop.step, Joystick-Detent.step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]
2026-05-18 Add configurable backlash filtering for axis handwheel encoders
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2026-05-31 Add a link to joystick photo and mention M3 bolts
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2026-08-16 Fix joystick PCB link
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
